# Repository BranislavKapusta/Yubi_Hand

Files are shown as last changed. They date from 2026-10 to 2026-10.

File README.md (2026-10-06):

# Yūbi Hand
> [!NOTE]
> Hand description

_DSC2452
_DSC2464
_DSC2468
_DSC2042_Ins
_DSC2055_Ins
_DSC2036_Ins

## Build
> [!NOTE]
> About the whole build of the hand

### Finger module
_DSC2fsfsef389
wdawfsrdhgdrgrdg_Hawdwdadigh
Untitlryjtyjtyjthtrgrdged-1

### Hand palm
gdgsefawdawdwad
awffrhrgrdgdrgrd
Untitled-adawdda1_afeafwfef

#### Thumb
Untitlawdawdawwadsfded-1

## Controls
> [!NOTE]
> About controls

---
Free for personal and non-commercial use, see LICENSE

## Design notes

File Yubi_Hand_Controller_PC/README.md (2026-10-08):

# Yūbi Hand Control with PC via Bluetooth
> [!WARNING]
> This is not currently describing the Controller but only the type of communication

This is control program for Yubi Hand project (prosthetic hand)

## Control messages sent via Serial and Serial Bluetooth.

> **Note:** dont forget to check if the /n is sent or not.

### `POS001` — Position Control

Sets individual positions for each finger/joint, with a wait time before the next command executes.

**Format:**
```
TYPE, time, n1, n2, n3, n4, n5, n6, n7, n8
```

| Field | Description | Type | Range |
|---|---|---|---|
| `TYPE` | Command type — `POS001` | string | — |
| `time` | Wait time until next command executes | int | ms |
| `n1` | Index finger | int | `[0, 90]` |
| `n2` | Middle finger | int | `[0, 90]` |
| `n3` | Ring finger | int | `[0, 90]` |
| `n4` | Pinky finger | int | `[0, 90]` |
| `n5` | Thumb finger | int | `[0, 90]` |
| `n6` | Seing | int | `[0, 90]` |
| `n7` | Wrist 1 | int | `[55, 125]` |
| `n8` | Wrist 2 | int | `[55, 125]` |

> **Note:** `-1` means keep the old position.

**Example:**
```
POS001, 1000, 45, 45, 45, 45, -1, -1, -1, -1
```

---

### `GRIP01` — Grip Preset

Sets a predefined grip pose.

**Format:**
```
TYPE, POSE
```

| Field | Description | Type |
|---|---|---|
| `TYPE` | Command type — `GRIP01` | string |
| `POSE` | Grip pose | string |

**Available poses:**
- `open`
- `fist`
- `pinch`
- `3pinch`
- `point`
- `cilinder`
- `small_cilinder`
- `relax`

**Example:**
```
GRIP01, open
```

---

### `OFF001` — Motor On/Off

Turns a specific motor on or off.

**Format:**
```
TYPE, CMD, MotorIndex
```

| Field | Description | Type | Range |
|---|---|---|---|
| `TYPE` | Command type — `OFF001` | string | — |
| `CMD` | `ON` or `OFF` | string | — |
| `MotorIndex` | Motor index | int | `[0, 7]` |

**Example:**
```
OFF001, off, 6
```

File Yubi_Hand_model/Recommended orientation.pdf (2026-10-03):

## Recommended orientation – Fingers without Pads

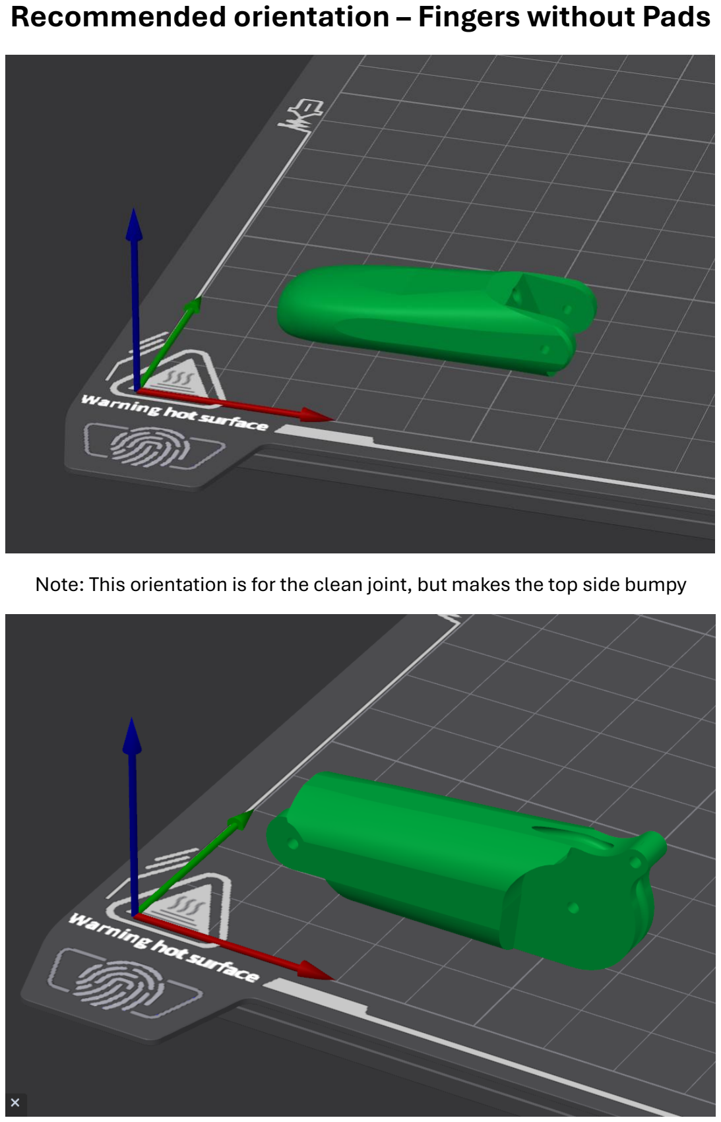
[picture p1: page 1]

Note: This orientation is for the clean joint, but makes the top side bumpy

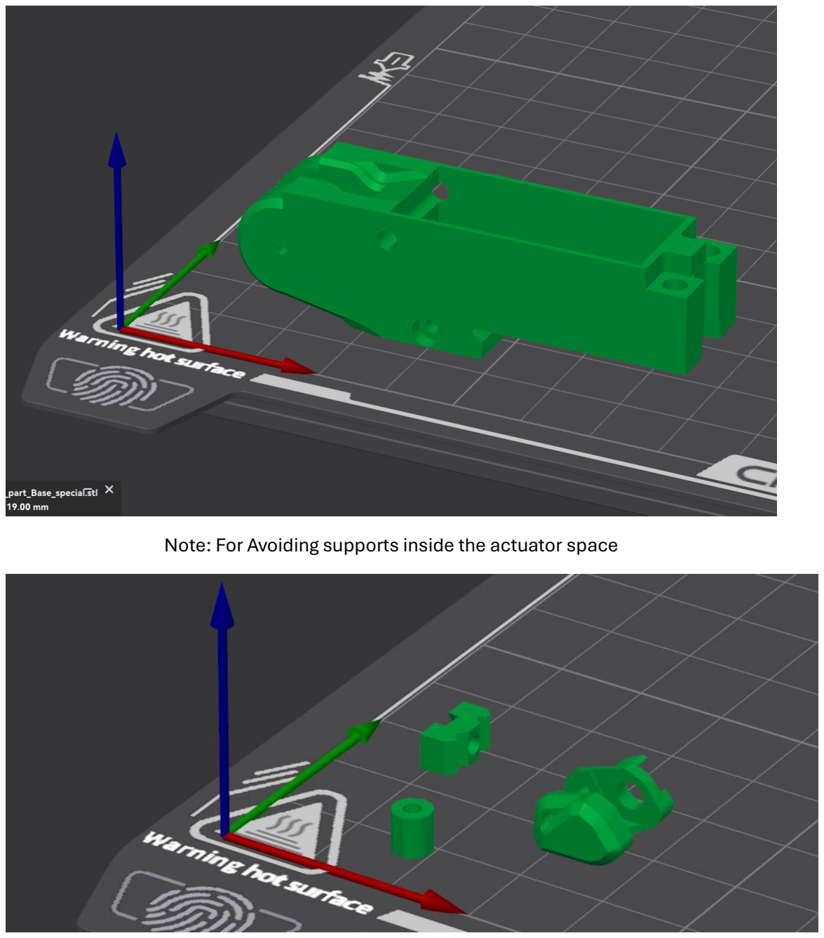
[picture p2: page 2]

Note: For Avoiding supports inside the actuator space

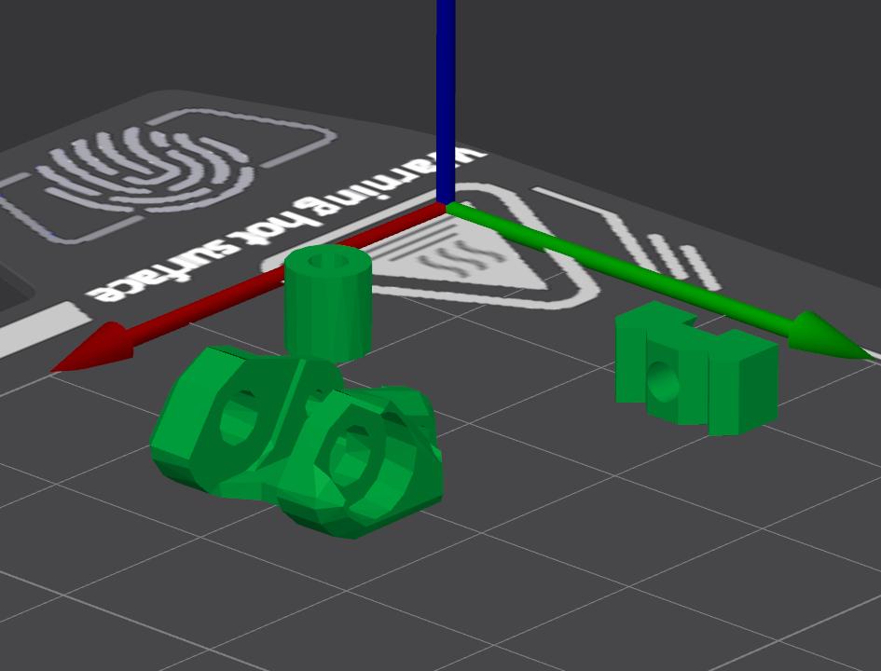
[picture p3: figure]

Note: Actuator link orientation is for structural strength and to not get support inside for the smooth connection

## Recommended orientation – Fingers with Pads Only change is the last finger part

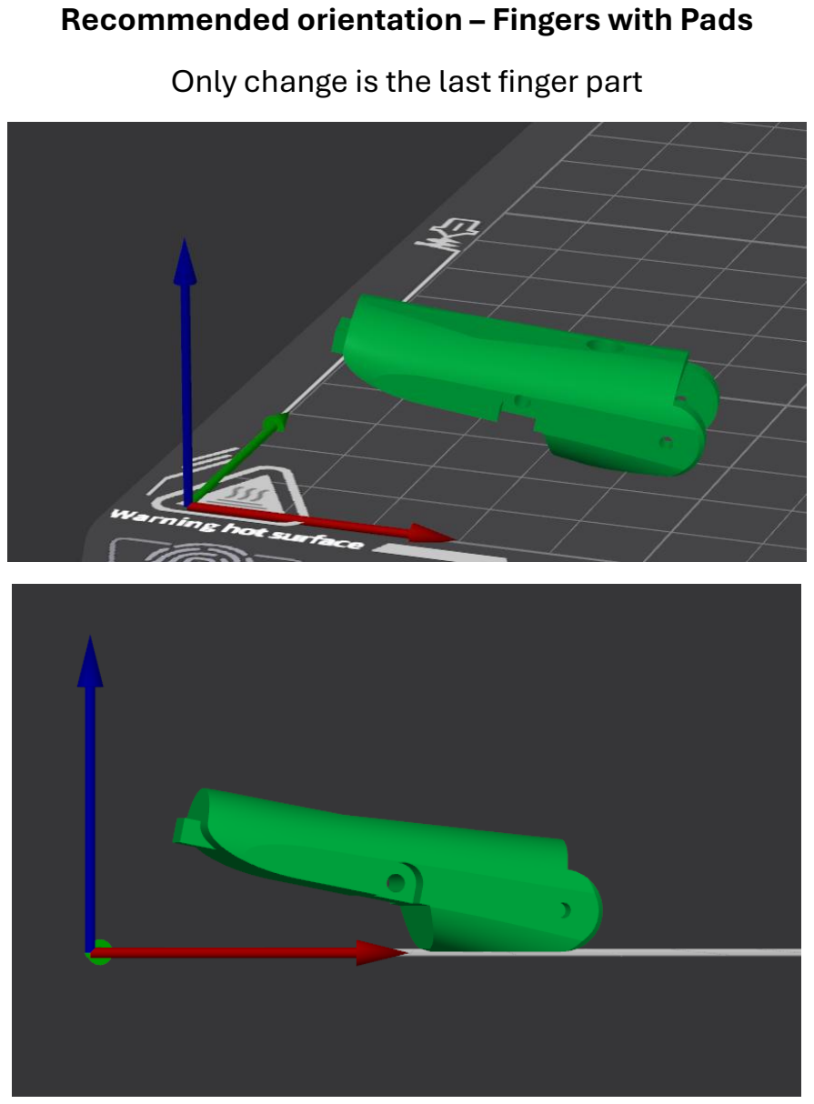
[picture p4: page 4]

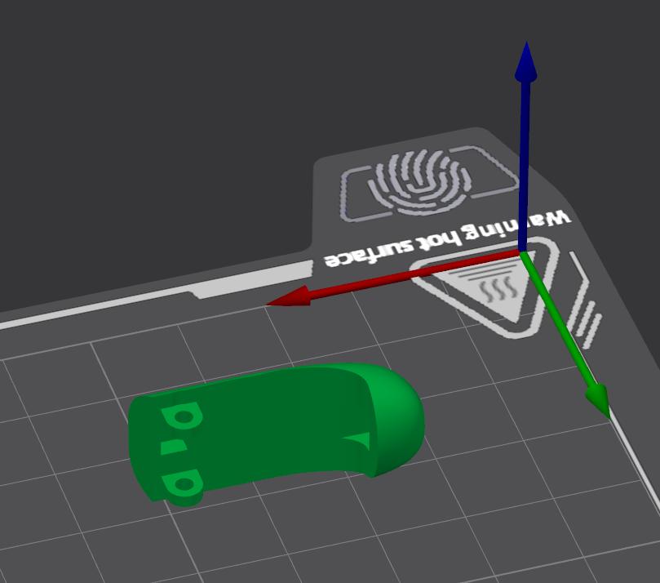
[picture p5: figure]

The TPE pad

## Recommended orientation – Palm

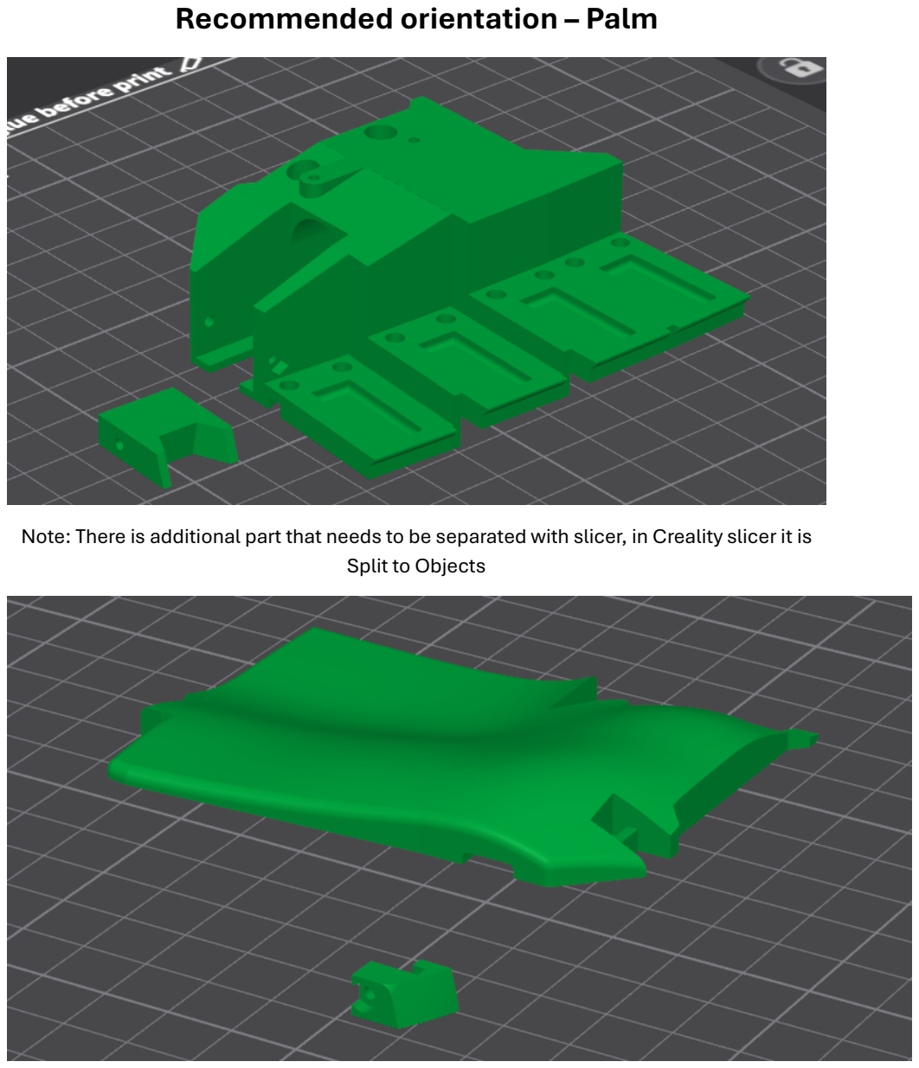
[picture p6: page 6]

Note: There is additional part that needs to be separated with slicer, in Creality slicer it is Split to Objects

## Recommended orientation – Thumb without Pads

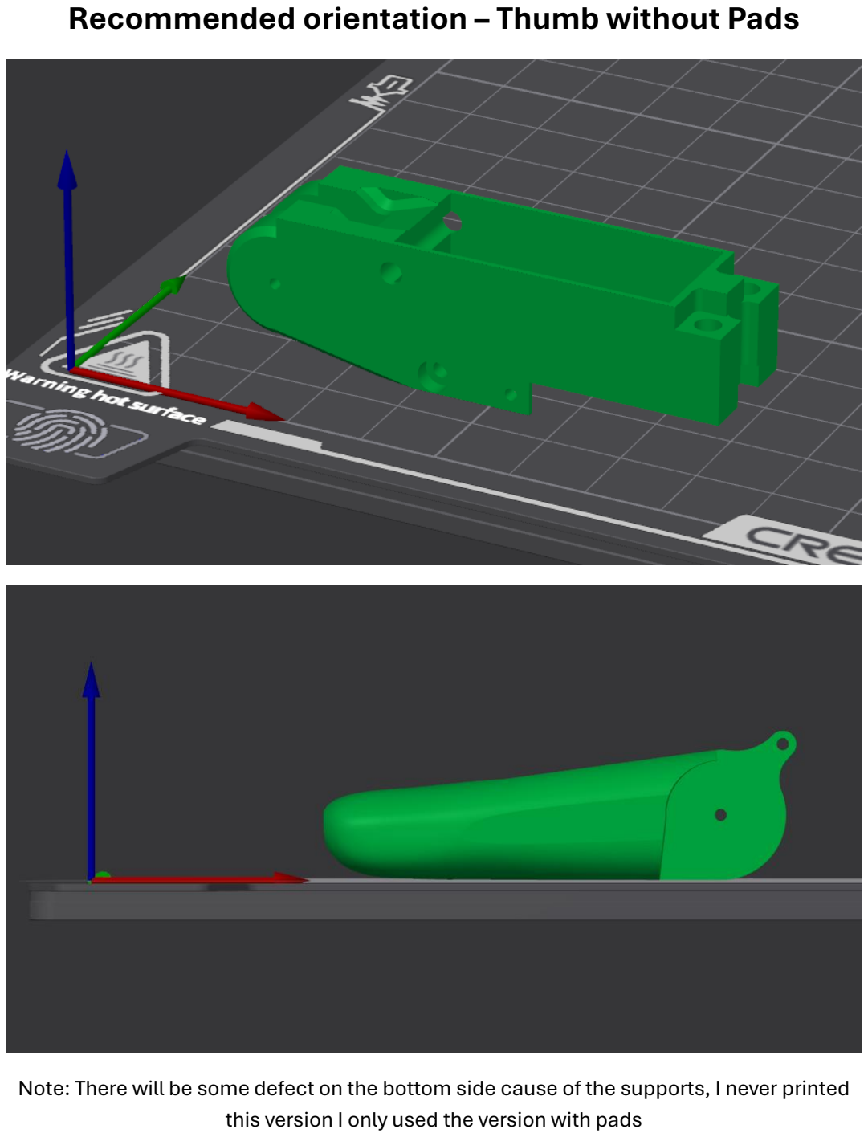
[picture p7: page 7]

Note: There will be some defect on the bottom side cause of the supports, I never printed this version I only used the version with pads

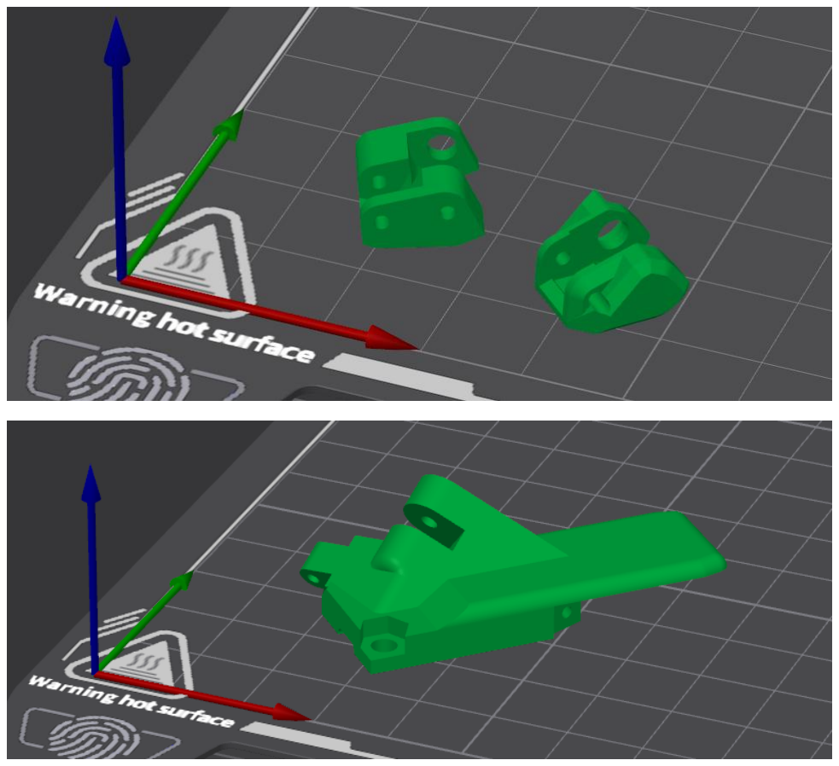
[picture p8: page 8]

## Recommended orientation – Thumb with Pads

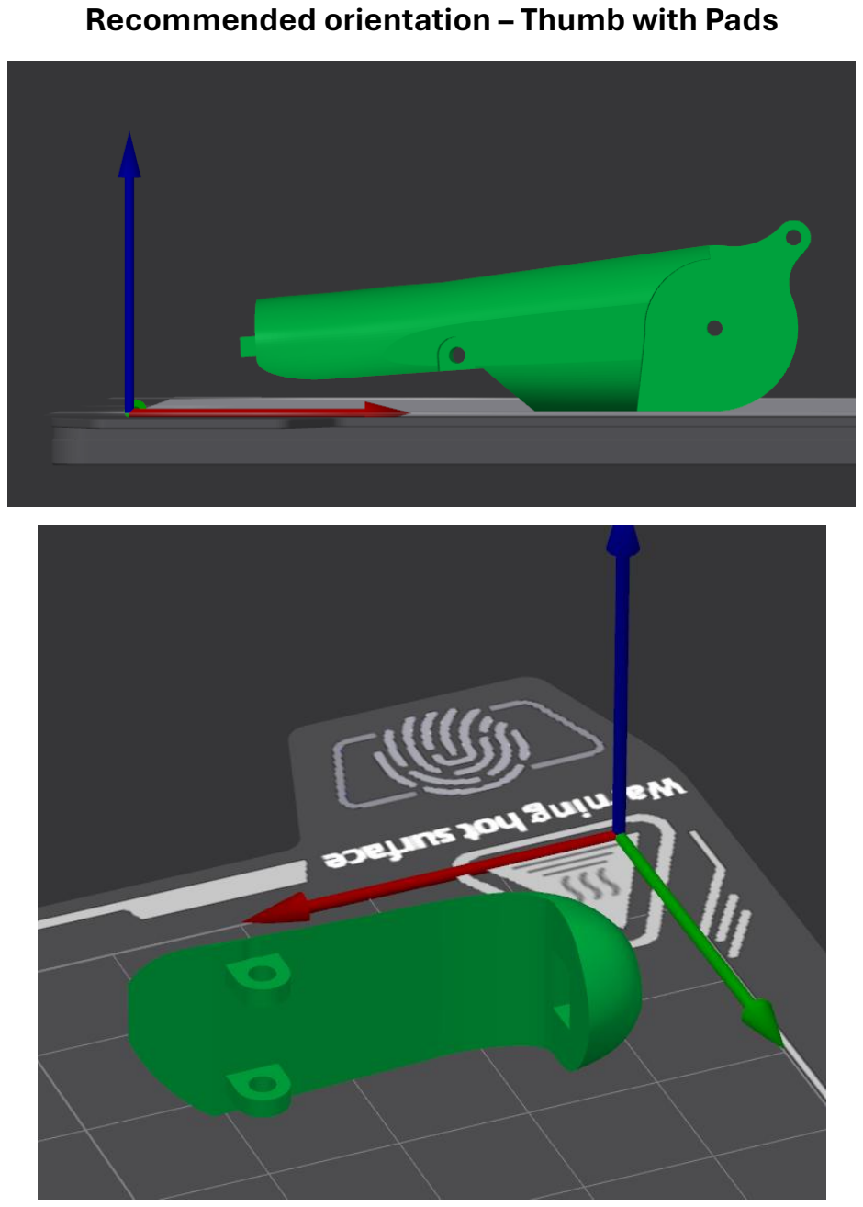
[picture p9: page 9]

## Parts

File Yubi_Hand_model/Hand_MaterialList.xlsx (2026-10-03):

Component name | Quantity | Note
DIN 439B M3 - M3 nut | 11
DIN 439B M2 - M2 nut | 7 | One extra for Thumb that will not be used
DIN 912 M3 x 16mm - M3 Screw | 11
DIN 912 M3 x 10mm - M3 Screw | 5
DIN 912 M2 x 10mm - M2 Screw | 5
DIN 912 M2 x 14mm - M2 Screw | 1
DIN 912 M2 x 20mm - M2 Screw | 1
DIN 913 M3 x 16mm - M3 Socket Set Screw | 6
DIN 913 M3 x 10mm - M3 Socket Set Screw | 1 | This is a special case where you can make this from the DIN 913 M3 x 16mm via cutting it, the hole is about 11.25mm and there arent any 11mm.
DIN 912 M2 x 5mm - M2 Screw | 4
DIN 912 M2 x 5mm - M2 Screw | 10 | When going with the TPE pads version
Hand crafted torsion springs from 5mm diametere spring | 4
Wire with 1.5mm diameter | /
String with 1mm to 1.5mm diameter | / | The holes are of a 2mm diameter size, so the size of the string is approximation

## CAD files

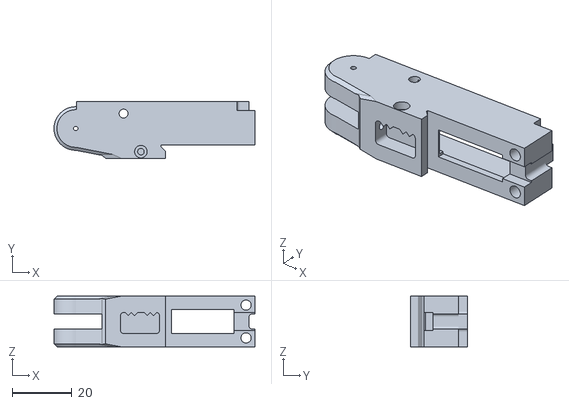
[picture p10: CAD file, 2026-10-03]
Yubi_Hand_model/Hand_Assembly/Finger_Module_withoutPads/Finger_part_Base_special.stl
67.3 x 19.0 x 17.0

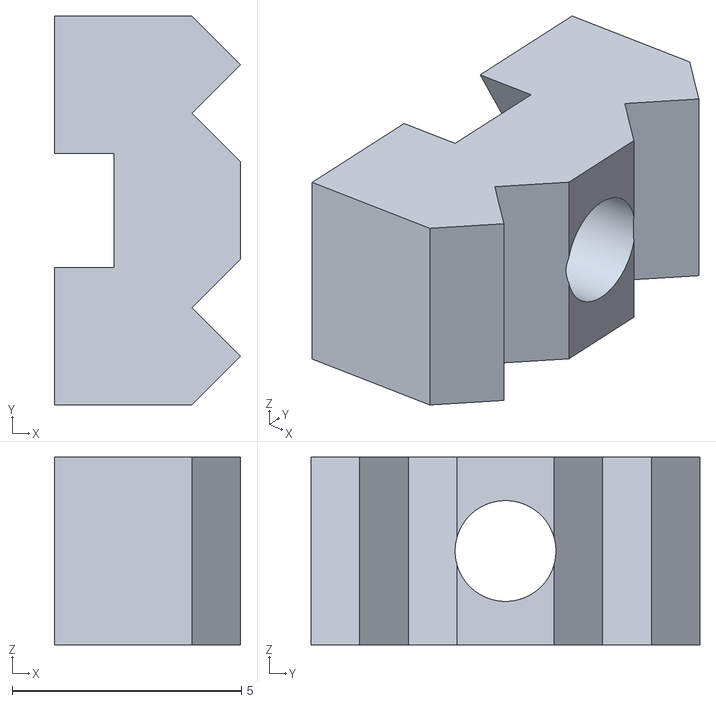
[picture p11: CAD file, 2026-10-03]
Yubi_Hand_model/Hand_Assembly/Finger_Module_withPads/Finger_part_Base_stringLock.stl
4.06 x 8.49 x 4.10

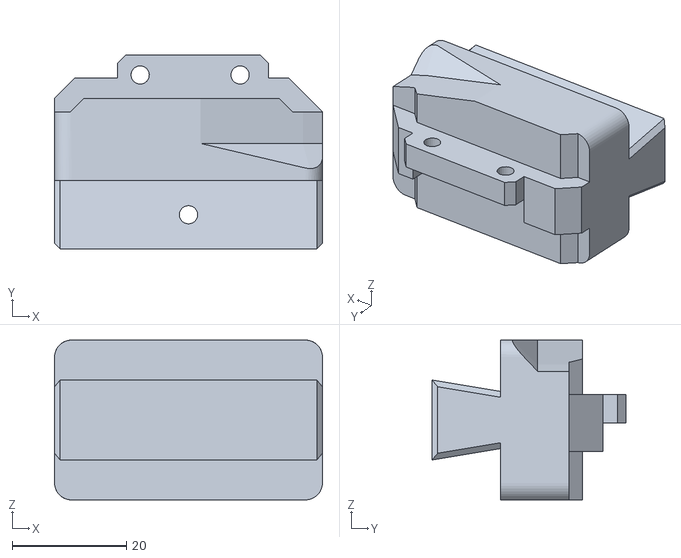
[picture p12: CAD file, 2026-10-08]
Yubi_Hand_model/Hand_Assembly/Mounting/Hand_Mount_p1.stl
46.9 x 34.0 x 28.0

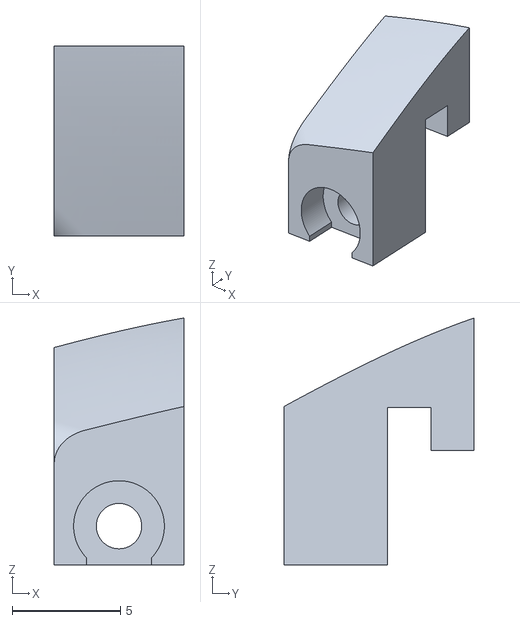
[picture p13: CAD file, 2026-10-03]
Yubi_Hand_model/Hand_Assembly/Palm/Hand_Palm_3_lock.stl
6.00 x 8.80 x 11.4

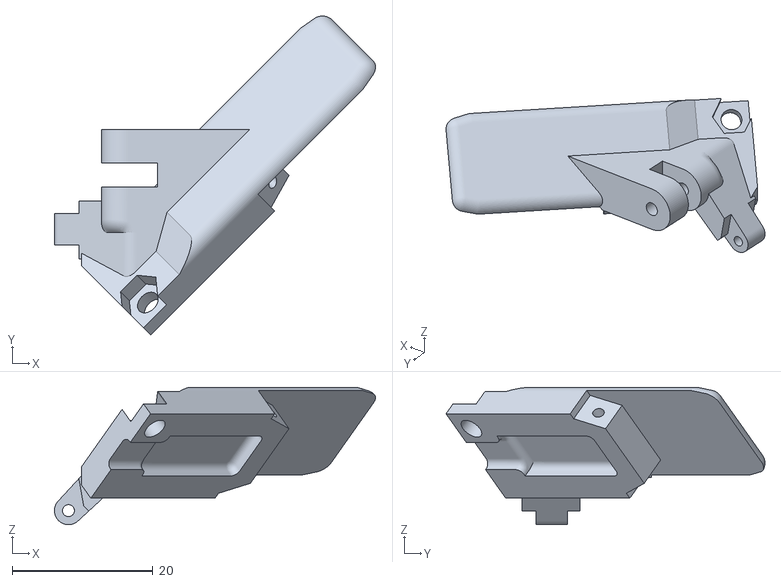
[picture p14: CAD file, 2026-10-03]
Yubi_Hand_model/Hand_Assembly/Thumb_withoutPad/ThumbRotatorBase_part_Comb_v3.stl
45.7 x 45.4 x 19.6

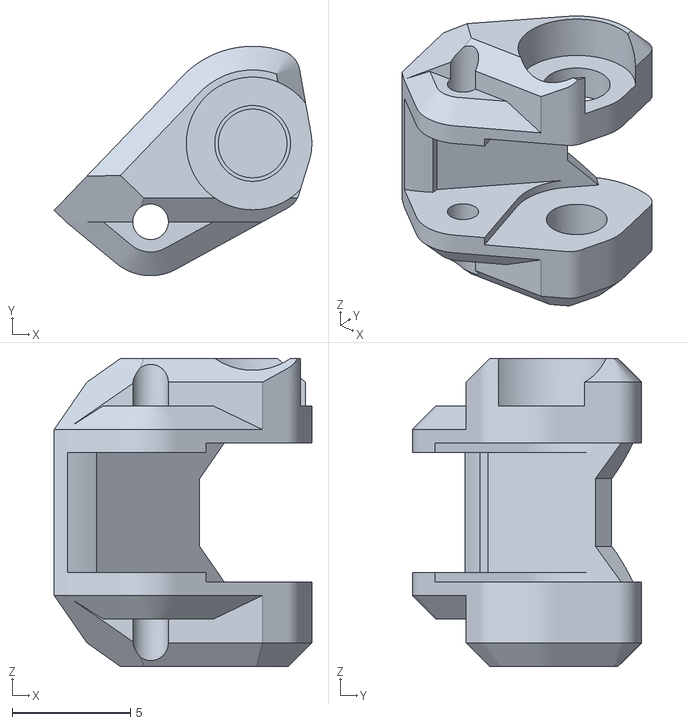
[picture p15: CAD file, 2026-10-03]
Yubi_Hand_model/Hand_Assembly/Tumb_withPad/Finger_part_ActuatorLink_v2.stl
10.9 x 9.68 x 13.0

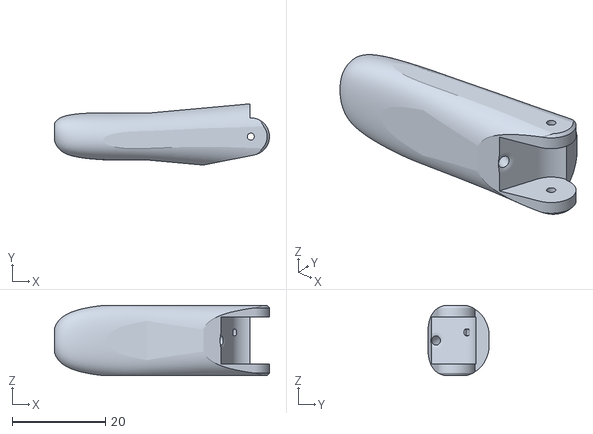
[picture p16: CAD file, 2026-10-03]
Yubi_Hand_model/Hand_Assembly/Finger_Module_withoutPads/Finger_part_2.stl
46.0 x 13.1 x 15.0

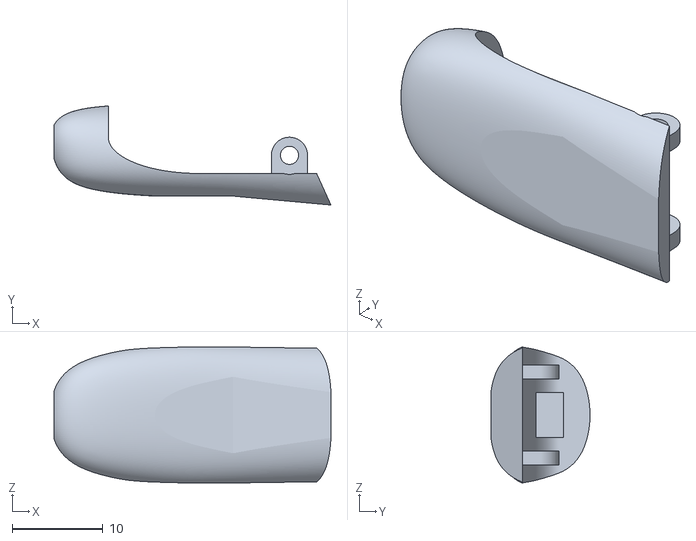
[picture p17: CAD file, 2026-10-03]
Yubi_Hand_model/Hand_Assembly/Finger_Module_withPads/Finger_part_2_Pad.stl
30.6 x 10.9 x 15.0

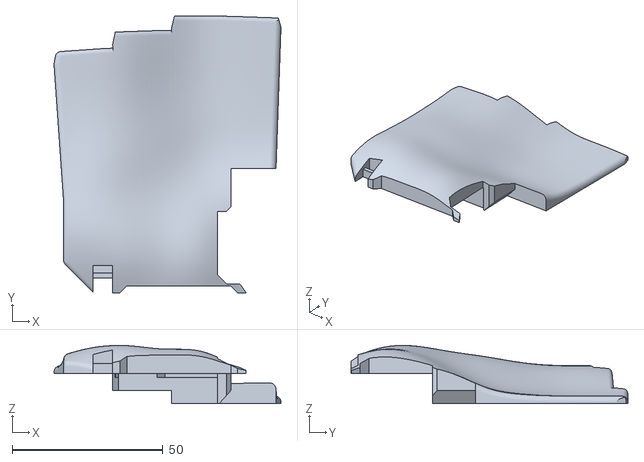
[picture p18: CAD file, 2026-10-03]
Yubi_Hand_model/Hand_Assembly/Palm/Hand_Palm_3.stl
75.3 x 91.8 x 19.3

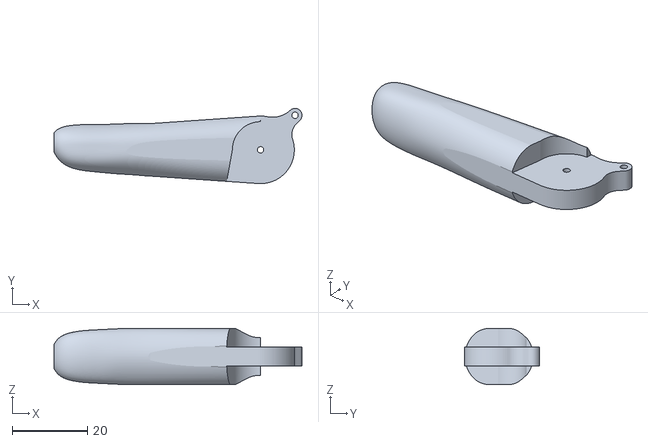
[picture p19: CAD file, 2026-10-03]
Yubi_Hand_model/Hand_Assembly/Thumb_withoutPad/Finger_thumb_part_oneUnit.stl
66.0 x 20.0 x 15.0

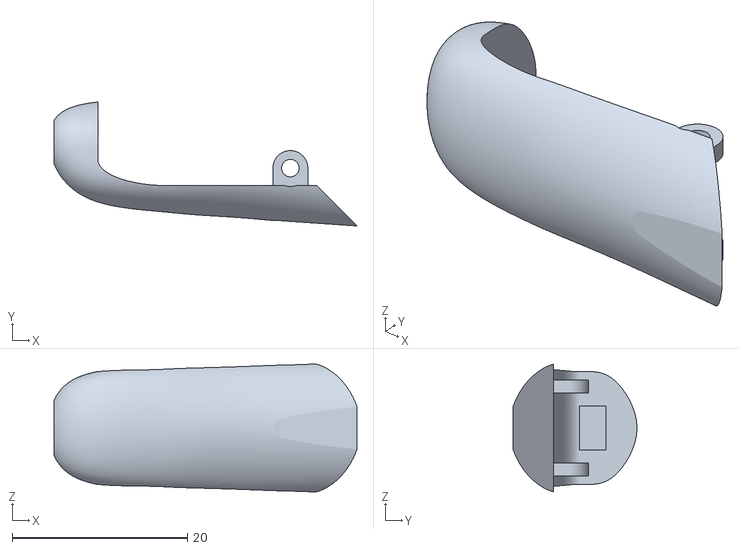
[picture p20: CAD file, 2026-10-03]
Yubi_Hand_model/Hand_Assembly/Tumb_withPad/Finger_thumb_part_oneUnit_Pad.stl
34.6 x 14.2 x 14.6

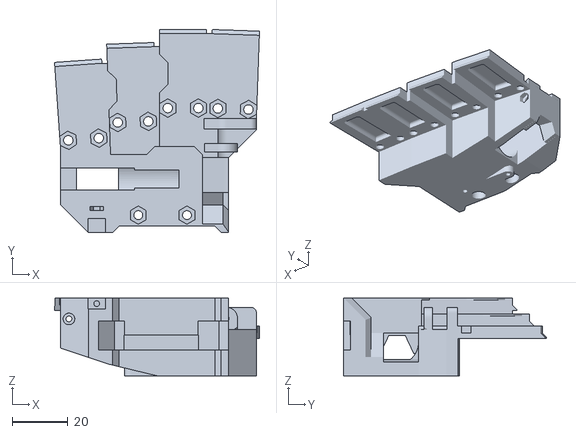
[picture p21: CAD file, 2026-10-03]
Yubi_Hand_model/Hand_Assembly_Model_URDF/meshes/Hand_Palm_2.stl
73.7 x 73.1 x 28.0

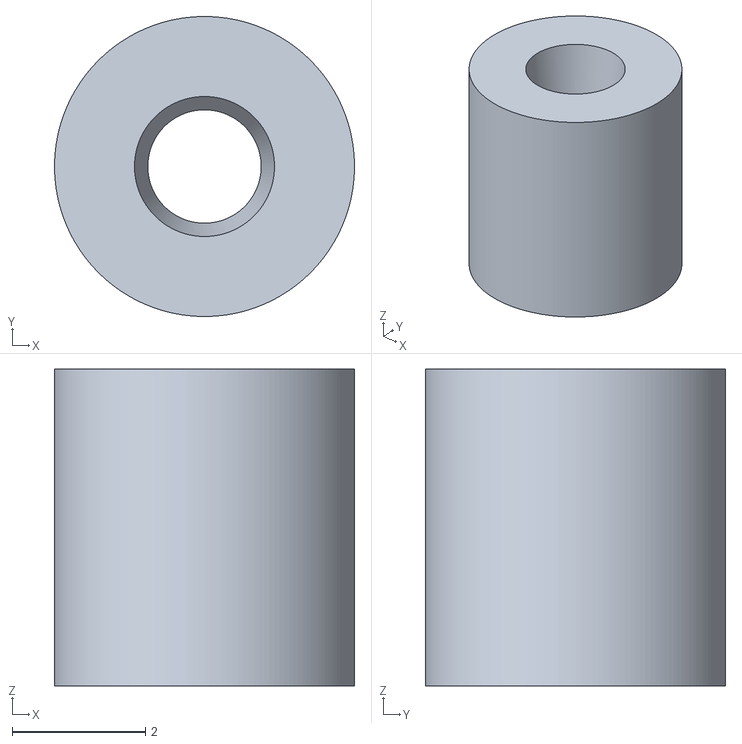
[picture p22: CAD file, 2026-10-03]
Yubi_Hand_model/Hand_Assembly/Finger_Module_withoutPads/Finger_part_springFiller_Experimental.stl
4.50 x 4.50 x 4.75

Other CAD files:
Yubi_Hand_model/Hand_Assembly_Model_URDF/meshes/ThumbRotatorBase_part_Comb_v3.stl
Yubi_Hand_model/Hand_Assembly/Palm/Hand_Palm_2.stl
Yubi_Hand_model/Hand_Assembly/Thumb_withoutPad/Thumb_part_Base_Special.stl
Yubi_Hand_model/Hand_Assembly/Tumb_withPad/Thumb_part_Base_Special.stl
Yubi_Hand_model/Hand_Assembly/Finger_Module_withPads/Finger_part_1.stl
Yubi_Hand_model/Hand_Assembly/Finger_Module_withPads/Finger_part_2_withPad.stl
Yubi_Hand_model/Hand_Assembly/Finger_Module_withoutPads/Finger_part_1.stl
Yubi_Hand_model/Hand_Assembly/Mounting/UR3s_50mm/Hand_Mount_plate_UR3e_50mm_v1.f3d
Yubi_Hand_model/Hand_Assembly/Mounting/UR3s_50mm/Hand_Mount_plate_UR3e_50mm_v1.step
Yubi_Hand_model/Hand_Assembly/Mounting/UR3s_50mm/Hand_Mount_plate_UR3e_50mm_v1.stl
Yubi_Hand_model/Hand_Assembly/Mounting/UR3s_50mm/Hand_Mount_plate_UR3e_50mm_v1_Spacer.step
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

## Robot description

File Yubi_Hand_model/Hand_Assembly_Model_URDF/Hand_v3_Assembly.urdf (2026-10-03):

<?xml version='1.0' encoding='utf-8'?>
<robot name="Hand_v3_Assembly">

    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
    <link name="Hand_Mount_plate_v2">
        <inertial>
            <origin xyz="-0.021801300876253597 -0.07659074890390893 0.005225757238851649" rpy="0.0 0.0 0.0" />
            <mass value="0.0928993354040722" />
            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
        </inertial>
        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
    </link>

    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
    <link name="Hand_Mount_p1">
        <inertial>
            <origin xyz="0.00043783538525168366 -0.00015522168230110023 0.016345920047245992" rpy="0.0 0.0 0.0" />
            <mass value="0.025902234704297027" />
            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
        </inertial>
        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
    </link>

    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
    <link name="Hand_Palm_2">
        <inertial>
            <origin xyz="0.00019421461378276605 -0.01795625190814511 0.004656821520625335" rpy="0.0 0.0 0.0" />
            <mass value="0.039955528778484704" />
            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
        </inertial>
        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
    </link>

    <link name="Hand_Palm_3">
        <inertial>
            <origin xyz="-0.0038337162798402157 0.031513217196976966 -0.008528785800387857" rpy="0.0 0.0 0.0" />
            <mass value="0.06732620296664459" />
            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
        </inertial>
        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
    </link>

    <link name="Hand_Palm_3_lock">
        <inertial>
            <origin xyz="-0.023866194076934483 0.009884262019643486 -0.022828717683895317" rpy="0.0 0.0 0.0" />
            <mass value="0.039046838388175936" />
            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
        </inertial>
        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
    </link>

    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
    <link name="Finger_Base_index">
        <inertial>
            <origin xyz="-3.4496898892921737e-06 0.004736775999703562 0.009057004017487543" rpy="0.0 0.0 0.0" />
            <mass value="0.007976429781331111" />
            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
        </inertial>
        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
    </link>

    <link name="Finger_p1_index">
        <inertial>
            <origin xyz="0.0032186989014055534 0.01760059733734403 -0.00033854591421677015" rpy="0.0 0.0 0.0" />
            <mass value="0.007285673416598265" />
            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
        </inertial>
        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
    </link>

    <link name="Finger_p2_index">
        <inertial>
            <origin xyz="-0.0042367954189414655 0.019851851266100767 -0.00012667433530598294" rpy="0.0 0.0 0.0" />
            <mass value="0.005200153834032561" />
            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
        </inertial>
        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
    </link>


    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
    <link name="Finger_tip_index">
        <origin xyz="0 0 0" rpy="0 -0 0"/>
        <inertial>
            <origin xyz="0 0 0" rpy="0 0 0"/>
            <mass value="1e-9"/>
            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
        </inertial>
    </link>

    <joint name="index_tip_fp2_joint" type="fixed">
        <origin xyz="0 0.0379 0.0048517" rpy="0 0 0"/>
        <parent link="Finger_p2_index"/>
        <child link="Finger_p2_index_tip"/>
        <axis xyz="0 0 0"/>
    </joint>
    

    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
    <link name="Finger_tip_thumb">
        <origin xyz="0 0 0" rpy="0 -0 0"/>
        <inertial>
            <origin xyz="0 0 0" rpy="0 0 0"/>
            <mass value="1e-9"/>
            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
        </inertial>
    </link>

    <joint name="thumb_tip_joint" type="fixed">
        <origin xyz="0.0339792 0.0383994 0.00312554" rpy="0 0 0"/>
        <parent link="Finger_thumb_part_oneUnit"/>
        <child link="Thumb_index_tip"/>
        <axis xyz="0 0 0"/>
    </joint>
    


    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
    <link name="Finger_Base_middle">
        <inertial>
            <origin xyz="-3.4524624801102187e-06 0.0047367759997035816 0.009057005624177314" rpy="0.0 0.0 0.0" />
            <mass value="0.007976429781331111" />
            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
        </inertial>
        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
    </link>

    <link name="Finger_p1_middle">
        <inertial>
            <origin xyz="0.0026024841795943567 0.01770220270457668 -0.00033854591421677796" rpy="0.0 0.0 0.0" />
            <mass value="0.007285673416598265" />
            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
        </inertial>
        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
    </link>

    <link name="Finger_p2_middle">
        <inertial>
            <origin xyz="-0.004927032124619818 0.019691898004442408 -0.0001266743353059774" rpy="0.0 0.0 0.0" />
            <mass value="0.005200153834032561" />
            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
        </inertial>
        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
    </link>

    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
    <link name="Finger_Base_ring">
        <inertial>
            <origin xyz="-3.447745693931914e-06 0.004736775999703553 0.009057003957394451" rpy="0.0 0.0 0.0" />
            <mass value="0.007976429781331111" />
            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
        </inertial>
        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
    </link>

    <link name="Finger_p1_ring">
        <inertial>
            <origin xyz="0.0019831039181047983 0.017782240931898157 -0.00033854591421675156" rpy="0.0 0.0 0.0" />
            <mass value="0.007285673416598265" />
            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
        </inertial>
        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
    </link>

    <link name="Finger_p2_ring">
        <inertial>
            <origin xyz="-0.005611268867555594 0.01950794962716687 -0.00012667433530595906" rpy="0.0 0.0 0.0" />
            <mass value="0.005200153834032561" />
            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
        </inertial>
        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
    </link>

    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
    <link name="Finger_Base_pinky">
        <inertial>
            <origin xyz="-3.447936721618916e-06 0.004736775999703563 0.00905700853866966" rpy="0.0 0.0 0.0" />
            <mass value="0.007976429781331111" />
            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
        </inertial>
        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
    </link>

    <link name="Finger_p1_pinky">
        <inertial>
            <origin xyz="0.0013612984050555622 0.01784062578165729 -0.00033854591421676294" rpy="0.0 0.0 0.0" />
            <mass value="0.007285673416598265" />
            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
        </inertial>
        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
    </link>

    <link name="Finger_p2_pinky">
        <inertial>
            <origin xyz="-0.00628866997537747 0.019300241252710997 -0.00012667433530596907" rpy="0.0 0.0 0.0" />
            <mass value="0.005200153834032561" />
            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
        </inertial>
        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
    </link>

    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
    <link name="ThumbRotatorBase_part_Comb_v3">
        <inertial>
            <origin xyz="0.008857068907936942 0.0011100386451895073 0.0032361341756280237" rpy="0.0 0.0 0.0" />
            <mass value="0.003939892277332412" />
            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
        </inertial>
        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
    </link>

    <link name="Thumb_part_Base">
        <inertial>
            <origin xyz="0.040274279625243936 -0.0085034597108057 0.004157010101590808" rpy="0.0 0.0 0.0" />
            <mass value="0.007966053114155389" />
            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
        </inertial>
        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
    </link>

    <link name="Finger_thumb_part_oneUnit">
        <inertial>
            <origin xyz="0.018257346658900407 0.015383343605187543 0.0015740624905692699" rpy="0.0 0.0 0.0" />
            <mass value="0.009434527038695552" />
            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
        </inertial>
        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
    </link>

    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
    <joint name="constrain_connector_to_base_link" type="fixed">
        <origin xyz="-0.02180131127702619 -0.0677686542039223 0.005230248977509285" rpy="-1.5707963267948968 0.0 0.0" />
        <parent link="Hand_Mount_plate_v2" />
        <child link="Hand_Mount_p1" />
    </joint>

    <joint name="constrain_palm_to_connector" type="fixed">
        <origin xyz="-0.0007876899999999965 0.0045000000000000005 0.034174869999999996" rpy="-1.5707963267948966 0.0 -3.141592653589793" />
        <parent link="Hand_Mount_p1" />
        <child link="Hand_Palm_2" />
    </joint>

    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
    <joint name="constrain_palm3_to_palm2" type="fixed">
        <origin xyz="-0.0019999999999999974 0.007499999999999995 0.018500000000000003" rpy="0.0 0.0 3.141592653589793" />
        <parent link="Hand_Palm_2" />
        <child link="Hand_Palm_3" />
    </joint>

    <joint name="constrain_palmlock_to_palm2" type="fixed">
        <origin xyz="0.02321702 0.004783729999999986 0.014500000000000002" rpy="-1.5707963267948966 0.0 0.0" />
        <parent link="Hand_Palm_2" />
        <child link="Hand_Palm_3_lock" />
    </joint>

    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
    <joint name="constrain_index_to_palm2" type="fixed">
        <origin xyz="-0.026847530000000026 -0.06296849 0.004" rpy="-1.5707963267948966 0.0 3.1066860685499065" />
        <parent link="Hand_Palm_2" />
        <child link="Finger_Base_index" />
    </joint>
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

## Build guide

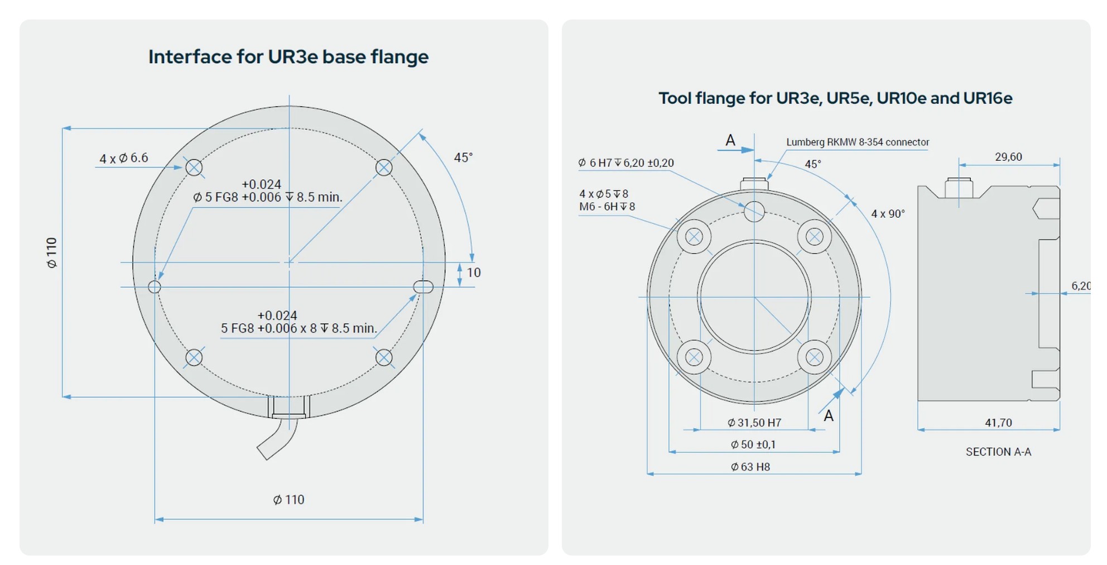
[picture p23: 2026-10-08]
Yubi_Hand_model/Hand_Assembly/Mounting/UR3s_50mm/base_tool_flange_dimensions_UR3s_UR5e_UR10e_UR16e.jpg

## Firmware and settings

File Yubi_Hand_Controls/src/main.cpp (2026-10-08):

#include <Arduino.h>
#include <ESP32Servo.h>
#include <WiFi.h>
#include <WebServer.h>
#include <BluetoothSerial.h>
#include <Wire.h>

#include "LittleFS.h"

#include "wifi_server.h"
#include "serial_com.h"
#include "bluetooth_com.h"

#include "finger_v2.h"
#include "wrist_v2.h"
#include "led_indicators.h"
#include "control.h"

//#include "orientation_sensor.h"
//#include "FastIMU.h"

//MPU6500 IMU1;
//calData calib1 = { 0 };


void setup() {
    Wire.begin();
    delay(1000); // needed for the wire initialization - dont know why

    init_serial_com();
    init_bluetooth_com();

    init_led_indicators();
    init_finger_motors_setup_v2();
    init_wrist_motors_setup_v2();

    init_wifi_sever_setup();

    init_fingers_wrist();

    //init_orientation_sensor();

}

void loop() {
    // Communications
    server.handleClient();
    check_serial_communication();
    check_bluetooth_communication();
    
    // Sensors
    //orientation_sensor_update();

    // Motor control
    control_movement();

    led_indicators_update();
}

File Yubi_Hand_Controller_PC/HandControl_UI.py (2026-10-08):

import serial
import time

import cv2
import mediapipe as mp
import os
import urllib.request
import warnings

import asyncio
import threading
import tkinter as tk
import ttkbootstrap as tb
from scipy.stats import alpha
from ttkbootstrap.widgets import Meter
from bleak import BleakClient

import math



#_________________________________________________________________
# CONFIGURATION
##################################################################

PORT = 'COM4'
bluetooth_PORT = 'COM7'
BAUD = 115200
TIMEOUT = 1

periodic_mode = False  # default: manual mode
periodic_speed = 250 # in milliseconds
hand_tracking = False
com_mode = "none"  # tracks which is active

getters = []
setters = []
hand_tracking_values = []

serial_com = None  # <-- add this here
bluetooth_com = None

# Suppress MediaPipe warnings
os.environ['TF_CPP_MIN_LOG_LEVEL'] = '3'
warnings.filterwarnings('ignore')

MODEL_PATH = "hand_landmarker.task"

def download_model_if_needed():
    if not os.path.exists(MODEL_PATH):
        print("Downloading hand landmarker model...")
        urllib.request.urlretrieve(
            "https://storage.googleapis.com/mediapipe-models/hand_landmarker/hand_landmarker/float16/1/hand_landmarker.task",
            MODEL_PATH
        )
        print("Done!")

#_________________________________________________________________
# INIT
##################################################################
def init_serial_com():
    serial_com = serial.Serial()
    serial_com.port = PORT
    serial_com.baudrate = BAUD
    serial_com.timeout = TIMEOUT
    serial_com.dtr = False
    serial_com.rts = False
    serial_com.open()  # open after setting DTR/RTS low

    print("Serial connection opened")

    return serial_com

def init_bluetooth_com():
    bluetooth_com = serial.Serial(bluetooth_PORT, BAUD, timeout=TIMEOUT)
    bluetooth_com.dtr = False
    bluetooth_com.rts = False

    print("Bluetooth serial connected on", bluetooth_PORT)

    return bluetooth_com

#_________________________________________________________________
# Functions
##################################################################
def distance(p1, p2):
    return math.sqrt((p1[0] - p2[0])**2 + (p1[1] - p2[1])**2)

def send_serial_command(serial,msg):
    print("Sending via serial com")
    #cmd = "POS001, 2000, 60, 40, 20, 0, 0, 0, 0, 0\nf"
    serial.write((msg + '\n').encode('utf-8'))

def send_bluetooth_command(bluetooth,msg):
    if bluetooth and bluetooth.is_open:
        print("Sending via Bluetooth com")
        #cmd = "POS001, 2000, 20, 0, 0, 30, 0, 0, 0, 0\nf"
        bluetooth.write((msg + '\n').encode('utf-8'))

def build_msg(marker="POS001",values = [],input_msg="---"):
    msg = ""

    if marker == "POS001":
        msg = msg + marker + ",0"
        for v in values:
            msg += ", " + str(v)

    if marker == "GRIP01":
        if not input_msg == "---":
            msg = msg + marker + "," + input_msg

    if marker == "SPEED1":
        msg = ""

    if marker == "OFF001":
        msg = ""

    print(f"Build Msg: {msg} ")

    return msg

def is_behind_perp(A, B, P):
    AB = (B[0] - A[0], B[1] - A[1])
    BP = (P[0] - B[0], P[1] - B[1])
    dot = AB[0]*BP[0] + AB[1]*BP[1]
    return dot < 0  # True if P is behind the perpendicular line at B

def hand_calculations(hand_points):
    global hand_tracking_values
    '''
    | ** 0 **  | WRIST              |   —       | Root reference point
    | ** 1 **  | THUMB CMC          | Thumb     | Base
    | ** 2 **  | THUMB MCP          | Thumb     | Knuckle
    | ** 3 **  | THUMB IP           | Thumb     | Middle joint
    | ** 4 **  | THUMB TIP          | Thumb     | --- Tip ---
    | ** 5 **  | INDEX FINGER MCP   | Index     | Knuckle
    | ** 6 **  | INDEX FINGER PIP   | Index     | Middle joint
    | ** 7 **  | INDEX FINGER DIP   | Index     | Lower joint
    | ** 8 **  | INDEX FINGER TIP   | Index     | --- Tip ---
    | ** 9 **  | MIDDLE FINGER MCP  | Middle    | Knuckle
    | ** 10 ** | MIDDLE FINGER PIP  | Middle    | Middle joint
    | ** 11 ** | MIDDLE FINGER DIP  | Middle    | Lower joint
    | ** 12 ** | MIDDLE FINGER TIP  | Middle    | --- Tip ---
    | ** 13 ** | RING FINGER MCP    | Ring      | Knuckle
    | ** 14 ** | RING FINGER PIP    | Ring      | Middle joint
    | ** 15 ** | RING FINGER DIP    | Ring      | Lower joint
    | ** 16 ** | RING FINGER TIP    | Ring      | --- Tip ---
    | ** 17 ** | PINKY MCP          | Pinky     | Knuckle
    | ** 18 ** | PINKY PIP          | Pinky     | Middle joint
    | ** 19 ** | PINKY DIP          | Pinky     | Lower joint
    | ** 20 ** | PINKY TIP          | Pinky     | --- Tip ---
    '''

    # Index - Middle - Ring - Pinky
    ##################################################################
    d_wrist_1 = distance([hand_points[0].x,hand_points[0].y], [hand_points[5].x,hand_points[5].y])
    d_wrist_2 = distance([hand_points[0].x,hand_points[0].y], [hand_points[9].x,hand_points[9].y])
    d_wrist_3 = distance([hand_points[0].x,hand_points[0].y], [hand_points[13].x,hand_points[13].y])
    d_wrist_4 = distance([hand_points[0].x,hand_points[0].y], [hand_points[17].x,hand_points[17].y])

    d_index_finger = distance([hand_points[5].x,hand_points[5].y], [hand_points[8].x,hand_points[8].y])
    d_middle_finger = distance([hand_points[9].x,hand_points[9].y], [hand_points[12].x,hand_points[12].y])
    d_ring_finger = distance([hand_points[13].x,hand_points[13].y], [hand_points[16].x,hand_points[16].y])
    d_pinky_finger = distance([hand_points[17].x,hand_points[17].y], [hand_points[20].x,hand_points[20].y])

    d_index = d_index_finger*1.15/d_wrist_1
    d_middle = d_middle_finger*1.1/d_wrist_2
    d_ring = d_ring_finger*1.2/d_wrist_3
    d_pinky =  d_pinky_finger*1.3/d_wrist_4

    d_over_index = is_behind_perp([hand_points[0].x,hand_points[0].y], [hand_points[5].x,hand_points[5].y],[hand_points[8].x,hand_points[8].y])
    d_over_middle = is_behind_perp([hand_points[0].x,hand_points[0].y], [hand_points[9].x,hand_points[9].y],[hand_points[12].x,hand_points[12].y])
    d_over_ring = is_behind_perp([hand_points[0].x,hand_points[0].y], [hand_points[13].x,hand_points[13].y],[hand_points[16].x,hand_points[16].y])
    d_over_pinky = is_behind_perp([hand_points[0].x,hand_points[0].y], [hand_points[17].x,hand_points[17].y],[hand_points[20].x,hand_points[20].y])

    #Switching
    if not d_over_index:
        angle_index = 80 - (d_index * 80)
    else:
        angle_index = 80 +  (d_index * 10)*5

    if not d_over_middle:
        angle_middle = 90 - (d_middle * 90)
    else:
        angle_middle = 80 + (d_middle * 10)*5

    if not d_over_ring:
        angle_ring = 80 - (d_ring * 80)
    else:
        angle_ring = 80 + (d_ring * 10)*5

    if not d_over_pinky:
        angle_pinky = 80 - (d_pinky * 80)
    else:
        angle_pinky = 80 + (d_pinky * 10)*5

    # Thumb - Swing
    ##################################################################
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

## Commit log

2026-10-03 Yubi Hand Model and Controls upload
    [Finger_part_1.stl, Finger_part_2.stl, Finger_part_2_Pad.stl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]
2026-10-06 Update README images
    Added images of the model and real assembly of the hand
2026-10-08 Mounting system for Hand (UR3e Universal robots)
    Connector/Adapter for the Hand for mounting on robotic arms and mount for tool flange UR3e (50mm). Multiple versions for different circumstances.
    [Hand_Mount_p1.stl, Hand_Mount_plate_UR3e_50mm_v1.f3d, Hand_Mount_plate_UR3e_50mm_v1.step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]
2026-10-08 Folder restructure & Hand control via PC (Bluetooth)
    [Finger_part_1.stl, Finger_part_2.stl, Finger_part_2_Pad.stl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]
2026-10-08 Update for the URDF
    [Hand_Mount_plate_v2.stl]
2026-10-08 Edit of naming
    [Finger_part_1.stl, Finger_part_2.stl, Finger_part_2_Pad.stl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]
2026-10-08 Spacers & Updated Geometry for Mouts
    Added scalable spacers and adjusted geometry of the mounts
    [Hand_Mount_plate_UR3e_50mm_v1.f3d, Hand_Mount_plate_UR3e_50mm_v1.step, Hand_Mount_plate_UR3e_50mm_v1.stl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]
2026-10-27 Adjusted and changed nameings for the mounting system
2026-11-11 LED indicators and changes
    Added LED indicators, converted WiFi communication style to one unified style. Every msg goes through process_communication function
